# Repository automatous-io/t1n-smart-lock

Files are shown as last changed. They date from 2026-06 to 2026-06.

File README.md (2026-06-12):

# T1N Smart Lock

The T1N Smart Lock is an open source Matter over Thread device designed
for the 2005 Dodge Sprinter 2500 (T1N chassis). It adds what the van never
had: lock and unlock from your iPhone, lock state you can see at a glance,
and a sensor for any door left ajar. It does this without driving the lock
motors directly or replacing the factory module. The factory keys and key fob
keep working exactly as before.

The factory service manual identifies the wires, but does not describe reading
the lock-state LEDs, using the central timer module (CTM) rail to tell when the
van is asleep, or pulsing the locks once or twice depending on state. That approach
is the idea behind this project. Every signal and timing it depends on was worked out
by hand, with a multimeter at the back of the master door lock switch and a long stretch
of testing in the van. The manual gives you the pinout; it does not give you the design.

This device reports observed reality, not commanded state. So your app reflects what
the van actually did, not just what it was told to do.

<p align="center">
  <a href="docs/media/t1n-smart-lock-demo.mp4">
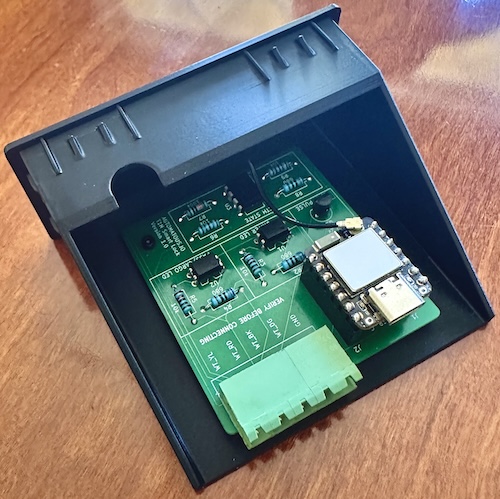
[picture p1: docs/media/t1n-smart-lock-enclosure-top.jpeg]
T1N Smart Lock in its 3D printed enclosure, top view
    
  </a>
  <br>
  <sub>Click to watch a short demo: opening/closing driver door, then locking and unlocking, with the master lock switch LEDs and Apple Home following each change.</sub>
</p>

It is built primarily for offgrid and vanlife use. It can run from either the
van's starter battery or a house/leisure battery; see
[INSTALL.md](docs/INSTALL.md#choosing-a-12v-source) for the tradeoffs.
It tolerates a noisy electrical environment including engine-on
conditions, and is a low-power Matter device so the power budget stays
small. It is local-first: it pairs and operates over Thread directly
from an iPhone 15 Pro or newer model featuring a Thread radio, and also
works through any compatible Thread Border Router for use in Apple Home,
Home Assistant, Google Home, or Alexa.

## How it works

The board is a small carrier for a Seeed Studio XIAO ESP32-C6, which
provides the Thread radio and runs the firmware. A transistor pulses
the factory master lock line, two optocouplers read the center console
switch LEDs without loading them, and a comparator turns the CTM sense
line into clean edges for sleep detection. The only connection to the
van is five wires tapped at the back of the master door lock switch,
landed on the board's five-position terminal block.

In your Matter app the device appears as a door lock plus two contact
sensors, one for the driver side and one for the passenger, cargo, and
rear doors. For the full architecture see [FIRMWARE.md](docs/FIRMWARE.md).

<p align="center">
  <a href="docs/media/t1n-smart-lock-home-with-doors.png">
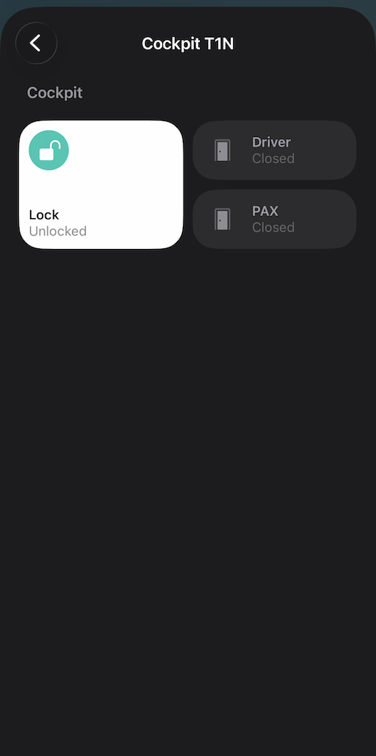
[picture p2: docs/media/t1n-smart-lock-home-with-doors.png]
The T1N Smart Lock in Apple Home, shown as a lock and two door sensors
    
  </a>
  <a href="docs/media/t1n-smart-lock-ha.png">
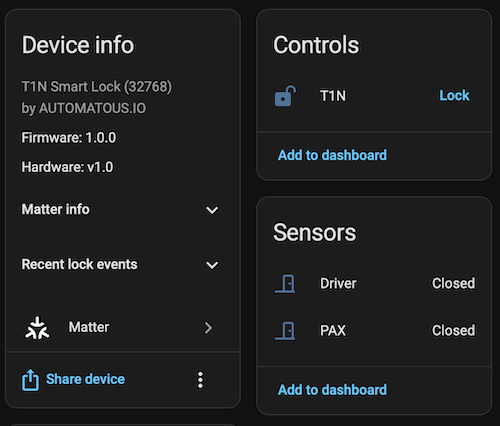
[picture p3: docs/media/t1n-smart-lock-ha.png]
The same lock paired in Home Assistant
    
  </a>
  <br>
  <sub>The same lock in Apple Home and Home Assistant. Matter is multi-admin, so it pairs to more than one ecosystem at once (see <a href="docs/INSTALL.md#commission-the-device">Commission the device</a>).</sub>
</p>

## Documentation

Everything is in [`docs/`](docs/). A typical path is to read SAFETY
first, build the board and enclosure, flash the firmware, then
commission and install it in the van.

| Document | What's in it |
|---|---|
| [FIRMWARE.md](docs/FIRMWARE.md) | firmware architecture and behavior |
| [HARDWARE.md](docs/HARDWARE.md) | PCB design, BOM, and ordering |
| [ENCLOSURE.md](docs/ENCLOSURE.md) | 3D printed enclosure |
| [BUILDING.md](docs/BUILDING.md) | building and flashing the firmware |
| [INSTALL.md](docs/INSTALL.md) | commissioning and van installation |
| [SAFETY.md](docs/SAFETY.md) | electrical and operational safety |
| [CERTIFICATION.md](docs/CERTIFICATION.md) | Matter/Thread certification status |
| [CONTRIBUTING.md](docs/CONTRIBUTING.md) | how to contribute |
| [LICENSING.md](docs/LICENSING.md) | license terms |

## Repository layout

| Path | Contents |
|---|---|
| [`firmware/`](firmware/) | C++ application on ESP-IDF (C/C++), source in `main/` |
| [`hardware/`](hardware/) | KiCad project, schematic, and gerbers |
| [`enclosure/`](enclosure/) | 3D printed enclosure model files |
| [`docs/`](docs/) | all project documentation |

## Status and compatibility

This is v1.0 of a personal project, developed and
tested by a single maintainer. It is an uncertified Matter device that
uses public test credentials, which is normal for a self-built device
and explained in [CERTIFICATION.md](docs/CERTIFICATION.md). Response
times on issues vary.

The firmware was developed and verified against one vehicle.
Compatibility with any other year, market, or trim is unconfirmed. If
you run it on a different T1N, a compatibility report is welcome. The
list below will grow as verified reports come in.

| Vehicle | Market | Status | Notes |
|---|---|---|---|
| 2005 Dodge Sprinter 2500 | North America | Verified | Reference build |

Firmware, PCB, and enclosure version history, and which revisions are
validated to work together, are recorded in [CHANGELOG.md](CHANGELOG.md).

## Safety

Installing this device modifies your vehicle's electrical system and
interfaces with the factory locking system. Wiring errors can damage
the CTM or the board. Read [SAFETY.md](docs/SAFETY.md) before building
or installing anything.

## Other projects from Automatous

| Project | What it is |
|---|---|
| [shelly-1-gen4-matter-thread](https://github.com/automatous-io/shelly-1-gen4-matter-thread) | open source Matter over Thread firmware for the Shelly 1 Gen4 |

## Licensing

This repository is multi-licensed. The firmware in `firmware/` is
[Apache 2.0](firmware/LICENSE.txt). The hardware in `hardware/` and the
enclosure in `enclosure/` are both CC BY 4.0
([hardware](hardware/LICENSE.txt), [enclosure](enclosure/LICENSE.txt)).
Both are open source. Use,
modification, sharing, and commercial use are all allowed, with
attribution. See [LICENSING.md](docs/LICENSING.md) for the plain
language version.

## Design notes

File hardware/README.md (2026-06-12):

# Hardware

KiCad design files and gerbers for the T1N Smart Lock PCB.
Licensed under [CC BY 4.0](LICENSE.txt).

See [HARDWARE.md](../docs/HARDWARE.md) for design notes, BOM, and
ordering instructions.

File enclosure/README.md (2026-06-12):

# Enclosure

3D printable enclosure that houses the T1N Smart Lock PCB and drops
into the factory center console opening. Designed for the T1N
center console; fit verified on a 2005, other years 2002 to 2006 should match but are
unconfirmed.

Licensed under [CC BY 4.0](LICENSE.txt).

Files included:
- STL file for direct printing
- STEP file for modification in CAD software

See [ENCLOSURE.md](../docs/ENCLOSURE.md) for print settings,
material recommendations, and assembly notes.

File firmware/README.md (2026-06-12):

# Firmware

ESP-IDF firmware for the T1N Smart Lock, a Matter over Thread
smart lock. Source is in `main/`.
Licensed under [Apache 2.0](LICENSE.txt).

See [FIRMWARE.md](../docs/FIRMWARE.md) for architecture and
behavior, and [BUILDING.md](../docs/BUILDING.md) for building the
firmware from source.

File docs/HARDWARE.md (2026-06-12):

# Hardware

**[README](../README.md)** > **Hardware** · [Report an issue](../../../issues/new)

PCB design files, bill of materials, and ordering notes for the
T1N Smart Lock board. For the 3D printed enclosure that houses
this board, see [ENCLOSURE.md](ENCLOSURE.md). For what the
firmware running on it does, see [FIRMWARE.md](FIRMWARE.md).

> Hardware design files are licensed under
> [CC BY 4.0](../hardware/LICENSE.txt). See [LICENSING.md](LICENSING.md#hardware-and-enclosure)
> for what that allows.

<p align="center">
  <a href="media/t1n-smart-lock-assembled.jpeg">
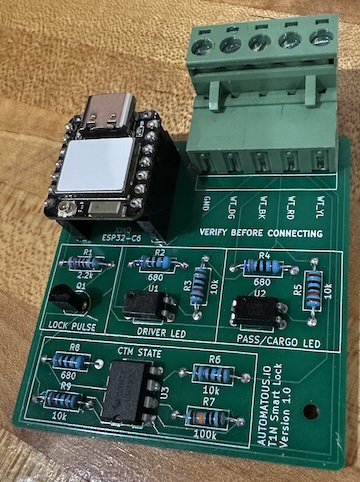
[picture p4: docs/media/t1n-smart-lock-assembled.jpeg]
Assembled board
    
  </a>
</p>

## What this board is

A small 2-layer carrier board for a Seeed Studio XIAO ESP32-C6.
The XIAO provides the Thread radio and runs the firmware; this
board adds the interface circuitry that lets the firmware observe
and command the Sprinter's factory central locking:

- A transistor output (Q1) that pulses the master lock line.
- Two optocouplers (U1, U2) that read the center console master door lock
  switch LEDs without electrically loading them.
- A comparator (U3) that turns the CTM's pulse-train sense line
  into clean digital edges for sleep detection.
- A 5-pin terminal block (J3) for the van-side wiring.

The XIAO is socketed on J1/J2, not soldered, so it can be swapped
or reflashed off-board. All components are through-hole and
hand-solderable. These are deliberate serviceability choices,
consistent across AUTOMATOUS.IO hardware and project designs.

## Board specifications

| Property | Value |
|---|---|
| Dimensions | 55.94 × 54 mm |
| Layers | 2 |
| Design tool | KiCad 10 |
| Controller | Seeed Studio XIAO ESP32-C6 (socketed) |
| Components | All through-hole, hand-solderable |
| Board revision | v1.0 |

## Schematic and layout

Design files live in `hardware/`:

- `hardware/kicad/`: KiCad 10 project (schematic + layout)
- `hardware/gerbers/`: fabrication outputs

[Schematic source (PNG)](../hardware/t1n-smart-lock-schematic.png) · [Schematic source (PDF)](../hardware/t1n-smart-lock-schematic.pdf)

## Power

> ⚠️ Connecting to vehicle 12V and the CTM carries real risks
> (miswiring, reverse polarity, CTM damage). Read
> [SAFETY.md](SAFETY.md) before wiring anything.

> The board draws ~0.3W continuously (~0.027A at 12V, measured at
> the buck input), since the Thread radio stays on. That is small
> enough to run from almost any 12V source. The reference build
> powers it from a 100Ah house/leisure battery. Whether a starter
> battery is also suitable depends on how often you drive; see
> [INSTALL.md](INSTALL.md#choosing-a-12v-source) for the tradeoff.

The board has no 12V input and no onboard 12V→5V stage. Power comes
in through the XIAO's USB-C connector, from an external buck
converter:

```
12V source  →  buck converter (12V → 5V, USB-C out)  →  XIAO USB-C
            →  XIAO onboard 5V→3V3 regulator  →  3V3 rail on this board
```

The 3V3 rail from the XIAO powers the optocoupler pull-ups and the
LM393. **12V never reaches this PCB.** J3 carries only the four van
signal wires plus ground; there is no power conductor on J3.

The buck converter is any quality automotive 12V→5V USB-C step-down.
Look for over-current and overvoltage protection; reverse-polarity
protection on the 12V input is also worth having, since a miswired
battery tap can otherwise damage the converter. It is external and
not part of this board's BOM.

## GPIO map

How the XIAO's pins connect to the board. This mirrors the pin
assignments in [FIRMWARE.md](FIRMWARE.md#hardware-interfaces).

| GPIO | Direction | Function | Circuit |
|---|---|---|---|
| 1 | Output | Master lock pulse | Drives Q1 base via R1 (2.2k) |
| 2 | Input | CTM sleep sense | LM393 (U3A) output, R9 pull-up |
| 18 | Input | Pass/cargo LED sense | PC817 (U2) collector, R5 pull-up |
| 20 | Input | Driver LED sense | PC817 (U1) collector, R3 pull-up |
| 3 | Output | RF switch enable | XIAO onboard antenna switch |
| 14 | Output | Antenna select (external U.FL) | XIAO onboard antenna switch |
| 15 | Output | Status LED | XIAO onboard LED |
| 9 | Input | Factory reset button | XIAO onboard BOOT button |

GPIO3, 14, 15, and 9 are internal to the XIAO module and do not
connect to this board's circuitry; they are listed for a complete
picture of pin usage.

## J3 terminal wiring

> ⚠️ Wiring errors can damage the CTM or board; see [SAFETY.md](SAFETY.md).

J3 is the only connection between the board and the van. The five
terminals, **in silkscreen order, left to right as printed on the board**,
are:

| Silkscreen | Signal | Connects to | Purpose |
|---|---|---|---|
| GND | Ground | Van chassis / CTM ground | Shared signal reference |
| WT_DG | Pass/cargo LED | Master door lock switch pass/cargo LED line | Read via U2 → GPIO18 |
| WT_BK | Driver LED | Master door lock switch driver LED line | Read via U1 → GPIO20 |
| WT_RD | CTM sense | CTM pulse-train line | Sleep detection via U3A → GPIO2 |
| WT_YL | Master lock | Master lock pulse line | Driven by Q1, pulsed from GPIO1 |

> The board silkscreen reads `GND · WT_DG · WT_BK · WT_RD · WT_YL`
> left to right. In the schematic, J3 pin 1 is `WT_YL` and pin 5 is
> `GND` (opposite order, since the connector is drawn from the other
> side). **Wire by the silkscreen, not the schematic pin numbers,**
> and confirm each signal before connecting. The board is printed
> `VERIFY BEFORE CONNECTING` for this reason. The `WT_*` labels are
> named for the factory wire colors they tap (Dodge base-with-tracer
> codes, so `WT_YL` is the white wire with a yellow tracer), but colors
> vary by year, market, and trim. Van-side wire colors, tap points, and
> the full wiring table are in [INSTALL.md](INSTALL.md#identifying-the-van-wires).

## Circuit blocks

**Master lock pulse (Q1).** GPIO1 drives the base of Q1 (PN2222A)
through R1 (2.2k). Q1's collector pulls the WT_YL master lock line
to ground for the pulse duration; the emitter is grounded. The
firmware drives GPIO1 low at init so the line is never floating
during boot (see `lock_pulse.cpp`). v1.0 has no base pull-down
resistor; float is handled in firmware.

**LED sense (U1, U2).** Each center console master-lock LED line drives
the input side of a PC817 optocoupler through a 680Ω series
resistor (R2 for driver/WT_BK, R4 for pass-cargo/WT_DG). The output
transistor pulls the GPIO low when the LED is lit, with R3 / R5
(10k) pulling the GPIO high otherwise. Optoisolation means the
board reads the LEDs without loading the van's wiring. U1 → GPIO20
(driver), U2 → GPIO18 (pass/cargo).

**CTM sleep detection (U3).** WT_RD carries a pulse train whose
frequency encodes whether the CTM is awake. R6 (10k) pulls WT_RD up
to the non-inverting input of comparator U3A (LM393). R7 (100k) and
R8 (680Ω) form a divider on the inverting input that sets the
comparison threshold. U3A's open-collector output drives GPIO2,
with R9 (10k) pulling the line up to 3V3, giving the firmware clean
digital edges to count. Only
half of the dual LM393 is used: U3A is active, U3B's inputs are
tied off, and U3C represents the shared power pins. Detail of the
firmware's edge-counting and sleep classifier is in
[FIRMWARE.md](FIRMWARE.md#what-the-firmware-observes).

## Bill of materials

### Board components

<p align="center">
  <a href="media/t1n-smart-lock-pcb.png">
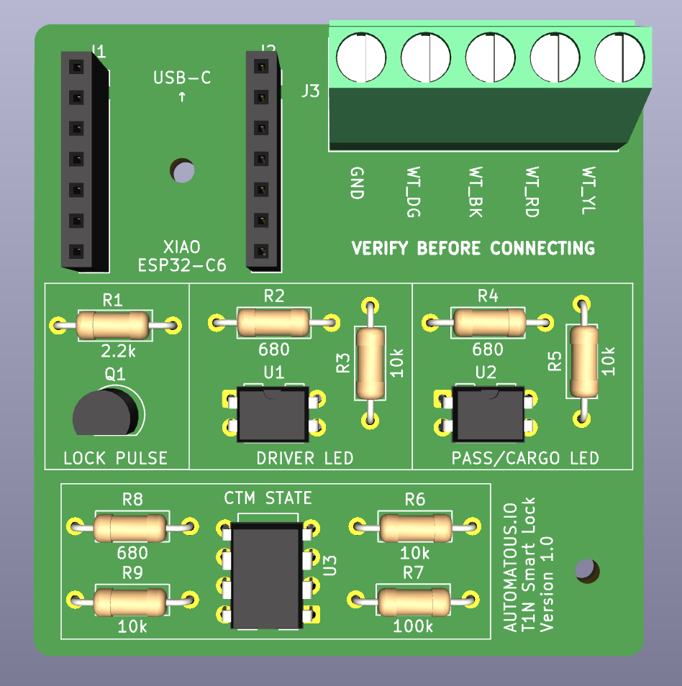
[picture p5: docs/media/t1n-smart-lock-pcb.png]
PCB render
    
  </a>
</p>

Soldered onto the PCB. All through-hole, hand-solderable.

| Ref | Qty | Type | Value | Footprint |
|---|---|---|---|---|
| J1, J2 | 2 | Socket header | 1×7, 2.54mm | PinSocket 1×07 P2.54mm vertical |
| J3 | 1 | Terminal block (see note) | 5.08mm, 5-pos | Phoenix MKDS-1,5-5-5.08 1×05 horizontal |
| Q1 | 1 | NPN transistor | PN2222A | TO-92 inline |
| R1 | 1 | Resistor | 2.2k | Axial DIN0207, P10.16mm |
| R2, R4, R8 | 3 | Resistor | 680Ω | Axial DIN0207, P10.16mm |
| R3, R5, R6, R9 | 4 | Resistor | 10k | Axial DIN0207, P10.16mm |
| R7 | 1 | Resistor | 100k | Axial DIN0207, P10.16mm |
| U1, U2 | 2 | Optocoupler | PC817 | DIP-4, W7.62mm |
| U3 | 1 | Dual comparator | LM393 | DIP-8, W7.62mm |

> **J3 terminal options.** The footprint is drawn for a fixed
> 5.08mm screw terminal (Phoenix MKDS). A 5.08mm *pluggable*
> terminal also fits the same pad pitch (with slight body overhang)
> and disconnects as a unit for easier service; the reference build
> uses this. Either works, pick your preference.

### External parts

Not soldered to the board; needed for a working install.

| Part | Notes |
|---|---|
| Seeed Studio XIAO ESP32-C6 | Seats into the J1/J2 sockets. Runs the firmware. |
| External antenna (U.FL / IPEX) | Connects to the XIAO's U.FL antenna connector. The firmware routes RF to the external antenna (see [FIRMWARE.md](FIRMWARE.md#module-map)), so this is required, not optional. |
| Buck converter, 12V→5V USB-C | Powers the XIAO from 12V source. Any quality automotive unit; see [Power](#power). |
| Inline fuse, ~1A | In the 12V feed close to the tap. Sized to the feed wire to protect the added wiring, not the board; see [INSTALL.md](INSTALL.md#powering-the-board). |

## Ordering the PCB

<p align="center">
  <a href="media/t1n-smart-lock-bare.jpeg">
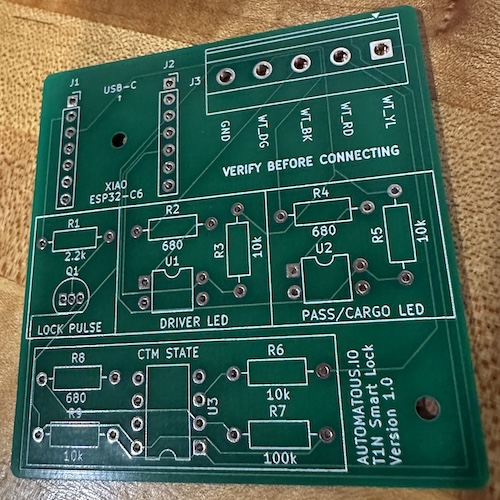
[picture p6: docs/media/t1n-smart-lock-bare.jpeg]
Bare PCB from fab
    
  </a>
</p>

The board was fabricated at JLCPCB from the gerbers in
`hardware/gerbers/`. Reference order: 30 pcs, 2-layer, standard
spec. Any 2-layer fab that accepts standard gerbers will work.
The board is hand-assembled; JLCPCB assembly is not required
since all parts are through-hole.

## Related documentation

- [README](../README.md) — project overview and quick start
- [FIRMWARE.md](FIRMWARE.md) — firmware architecture and behavior
- [ENCLOSURE.md](ENCLOSURE.md) — 3D printed enclosure
- [BUILDING.md](BUILDING.md) — building and flashing the firmware
- [INSTALL.md](INSTALL.md) — commissioning and van installation
- [SAFETY.md](SAFETY.md) — electrical and operational safety
- [CERTIFICATION.md](CERTIFICATION.md) — Matter/Thread certification status
- [CONTRIBUTING.md](CONTRIBUTING.md) — how to contribute
- [LICENSING.md](LICENSING.md) — license terms

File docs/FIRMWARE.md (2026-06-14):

# Firmware

**[README](../README.md)** > **Firmware** · [Report an issue](../../../issues/new)

This document explains the firmware architecture of the T1N Smart
Lock: how it observes vehicle state, how it commands the central
locking system, the design decisions that shaped the
implementation, and the validation that supports the v1.0 release.

The firmware runs on a XIAO ESP32-C6 and exposes the device to
Matter over Thread. It builds on Espressif's
[esp-matter](https://github.com/espressif/esp-matter) SDK and the
upstream OpenThread implementation. Application-specific code
lives in `firmware/main/`.

For the hardware this firmware drives, see
[HARDWARE.md](HARDWARE.md). For building and flashing, see
[BUILDING.md](BUILDING.md). For installation, see
[INSTALL.md](INSTALL.md). For safety, limitations, and failure modes,
see [SAFETY.md](SAFETY.md). A full list of related documents is in
[Related documentation](#related-documentation) at the end.

## Contents

- [Design philosophy](#design-philosophy)
- [Hardware interfaces](#hardware-interfaces)
- [Module map](#module-map)
- [Threading model](#threading-model)
- [The CTM model](#the-ctm-model)
  - [Stock CTM behavior](#stock-ctm-behavior)
  - [What the firmware observes](#what-the-firmware-observes)
  - [What the firmware commands](#what-the-firmware-commands)
  - [Why this approach](#why-this-approach)
- [The doors module](#the-doors-module)
  - [LED classification](#led-classification)
  - [Lock state derivation](#lock-state-derivation)
  - [Door state derivation](#door-state-derivation)
  - [Live vs stability-gated reads](#live-vs-stability-gated-reads)
  - [NVS persistence](#nvs-persistence)
  - [Blackout windows](#blackout-windows)
- [Lock command flow](#lock-command-flow)
  - [Command cooldown](#command-cooldown)
  - [Door open rejection](#door-open-rejection)
  - [Pulse count decision](#pulse-count-decision)
  - [The asymmetric pulse rule](#the-asymmetric-pulse-rule)
  - [Unlock command flow](#unlock-command-flow)
- [The pulse subsystem](#the-pulse-subsystem)
  - [Pulse width and sequence timing](#pulse-width-and-sequence-timing)
  - [Atomic single-sequence guarantee](#atomic-single-sequence-guarantee)
  - [Inter-sequence cooldown](#inter-sequence-cooldown)
  - [Boot-time safety](#boot-time-safety)
- [State reporting](#state-reporting)
  - [Observation push mechanism](#observation-push-mechanism)
  - [Optimistic write synchronization](#optimistic-write-synchronization)
  - [Eventual consistency](#eventual-consistency)
- [Building from source](#building-from-source)
- [Validation matrix](#validation-matrix)
- [Known limitations](#known-limitations)
- [Related documentation](#related-documentation)

## Design philosophy

The firmware is built on one core idea: report observed reality,
not commanded state.

Most aftermarket smart locks fire a command and assume it worked.
The Matter ecosystem then shows whatever the command requested,
which is correct most of the time and silently wrong the rest. A
pulse that didn't engage, a key fob that unlocked the van from
outside, a door that someone left open; these conditions silently
diverge from the optimistic state in the app.

The T1N Smart Lock takes a different approach. The Sprinter's
center console has master door lock switch (MLS) LEDs that already encode
the truth about lock and door state while the CTM is awake. The
firmware reads those LEDs the same way a human does, classifies
the patterns, and reports observed reality back to Matter. The
optimistic write from a Lock command is treated as a hypothesis
to be verified against observation, not a fact to be trusted.

This single decision shapes most of the architecture below. See
[SAFETY.md](SAFETY.md#what-the-firmware-adds-beyond-the-factory-system)
for how observation-first design bounds what the device can do wrong.

## Hardware interfaces

The lock and sensor interface uses four GPIO pins on the
ESP32-C6, each owned by a dedicated module (the antenna, status
LED, and reset button modules own additional pins, documented in
their own sections):

| GPIO | Direction | Module | Purpose |
|---|---|---|---|
| GPIO1 | Output | `lock_pulse` | Master lock pulse output |
| GPIO2 | Input | `ctm_state` | CTM sleep-detection signal |
| GPIO18 | Input | `doors` | PAX side MLS LED state |
| GPIO20 | Input | `doors` | Driver side MLS LED state |

GPIO ownership is exclusive; no module touches a pin that's owned
by another module. This keeps the interaction model clean and
makes it possible to reason about hardware safety properties
module by module.

The hardware design itself is documented in
[HARDWARE.md](HARDWARE.md), including the schematic, BOM, and
PCB layout. This document focuses on what the firmware does with
those signals.

## Module map

The firmware is organized into nine application-level modules
plus the Matter/CHIP stack provided by esp-matter:

**`app_main.cpp`** is the entry point. Configures Matter endpoints
(one door lock, two contact sensors), calls module init functions
in dependency order, starts the Matter stack.

**`lock_pulse`** owns GPIO1. Provides a non-blocking interface to
fire 1-pulse or 2-pulse sequences on the master lock line. An
internal worker task handles timing.

**`ctm_state`** owns GPIO2. Counts edges on the LM393 output,
applies a 5-second sliding window and sticky classifier, reports
whether the CTM is currently awake or asleep.

**`doors`** owns GPIO18 and GPIO20. Samples the MLS LEDs,
classifies each as SOLID, OFF, BLINK, or UNKNOWN, derives lock
and door states per side, persists state to NVS, pushes state to
Matter when observation diverges from the last reported value.

**`door_lock`** is the Matter Door Lock cluster glue. Receives
Lock/Unlock commands, applies command cooldown and door open
rejection, requests pulse sequences from `lock_pulse`, syncs the
optimistic state with the doors module's push tracker.

It also exposes `door_lock_init()`, an empty function whose only
job is to be called once from `app_main`. The cluster command
handlers (`emberAfPluginDoorLockOnDoorLockCommand` and friends)
are weak symbols that esp-matter resolves at link time; without
at least one symbol in this translation unit being referenced
directly, the linker would dead-strip the whole object file and
the handlers would silently vanish. The empty init call exists
only to anchor the file in the binary.

**`door_lock_manager`** holds credential, user, and schedule
storage for the Matter Door Lock cluster. The `BoltLockMgr` class
inside is vendored Espressif example code, used unchanged.
`door_lock` delegates PIN validation, credential operations, and
schedule management to this module.

**`status_led`** owns the XIAO ESP32-C6's onboard LED. Indicates
BLE advertising, Thread network state, and Matter Identify. The
blink patterns are tabulated in
[INSTALL.md](INSTALL.md#status-led-reference).

**`reset_button`** handles the factory reset button input. Clears
Matter commissioning data and restarts the device.

**`antenna`** routes the radio to the external U.FL antenna at boot:
GPIO3 enables the XIAO's onboard RF switch and GPIO14 selects the
external antenna over the built-in ceramic chip. It runs before the
Matter stack starts so the radio comes up on the right antenna, and
has no runtime behavior after that. The external antenna is what
extends Thread range, keeping the lock reachable for direct local
control from an iPhone 15 Pro or newer model featuring a Thread
radio, with no hub, consistent with the local-first design.

Modules communicate through narrow, explicit interfaces. The
doors module subscribes to `ctm_state` events via callback; the
door_lock module calls `lock_pulse_request`, `ctm_state_is_awake`,
and several `doors_*` accessors. There is no shared mutable
state outside the modules' own atomic variables.

## Threading model

The firmware runs on FreeRTOS with the following task topology:

| Task | Priority | Period/Trigger | Module | Purpose |
|---|---|---|---|---|
| `app_main` | (boot only) | once | `app_main` | Initialize subsystems, start Matter |
| Matter/CHIP | (managed) | event-driven | esp-matter | Matter protocol stack |
| `lock_pulse` | 10 | semaphore-driven | `lock_pulse` | Fire pulse sequences |
| `ctm_monitor` | 5 | 1000ms tick | `ctm_state` | Edge counting, classifier update |
| `doors_sample` | 5 | 50ms tick | `doors` | LED sampling and classification |
| `status_led` | 5 | 100ms tick | `status_led` | LED pattern updates |

Plus interrupts:

| ISR | Source | Module | Purpose |
|-----|---|---|---|
| GPIO2 edge | LM393 transition | `ctm_state` | Timestamp ring buffer append |

**Priority rationale.** The Matter/CHIP task runs at its default
priority (managed by esp-matter). `lock_pulse` runs at priority
10, higher than background monitor tasks so pulse timing is not
preempted by routine sampling, but lower than the CHIP task so
Matter work is never delayed by a pulse sequence. Background
monitor tasks (`ctm_monitor`, `doors_sample`, `status_led`) all
run at priority 5, which is sufficient for their periodic work.

**Cross-task safety.** State shared between tasks uses
`std::atomic` (default sequentially consistent ordering), with
`volatile` for the ISR-shared edge-timestamp ring buffer and for
the status LED module's simple cross-task state flags. There are
no traditional locks in the application code; the Matter stack
manages its own synchronization internally. The doors module is
the only place where multiple tasks might race (the sampler task
updates state, the door_lock task reads classifier output for the
BLINK check), and that race is safe because the reads are
point-in-time snapshots without compound state.

**Callback contract.** Modules that accept callbacks
(`ctm_state_register_callback`, `lock_pulse_register_complete_cb`)
fire the callback from the module's own task context. Callbacks
must not block. Implementations either set a flag or post to a
queue and return immediately. Blocking a callback delays the
module's primary work for the entire system.

## The CTM model

The central timer module (CTM) is the Sprinter's body control
unit. It handles central locking, interior lighting, the alarm
system, key fob processing, and various other low-voltage
functions. The CTM is the only component the firmware
communicates with; the rest of the vehicle's electrical system is
untouched.

### Stock CTM behavior

The CTM operates in two states: awake and asleep.

**Awake** is the active state. The center console MLS LEDs are
illuminated according to lock and door state. The CTM accepts
master lock pulses on the WT_YL line, responds to key fob
commands, processes door switch inputs, and continues to drive
any active loads (interior lights, etc.). The WT_RD signal,
traditionally the passenger-side (front passenger, slider, and
rear cargo) lock-pulse line, carries a pulse train at roughly
89 Hz when awake. The firmware repurposes WT_RD as a read-only
sleep-detection signal and never drives it.

**Asleep** is a power-saving state. After approximately 15
minutes of inactivity (no door switch activity, no MLS press, no
key fob event, no ignition), the CTM transitions to sleep. The
MLS LEDs go dark. The CTM is still powered and listening but
consumes minimal current. The WT_RD signal carries a slower pulse
train at approximately 47 Hz; this is how the firmware detects
sleep state.

The 15-minute timeout is typical but not universal. Locking the
van from inside via the door handle latches appears to trigger a
faster transition to sleep in edge cases; the CTM treats this as
a "the user has secured the vehicle and is leaving" signal. Other
variations exist across model years and trim levels.

Wake transitions happen on any of: a key fob press, a master door lock
switch press, a door switch event (any door opening or closing),
the ignition being turned on, or a master lock pulse on WT_YL
(the firmware's only output, via GPIO1). A passenger-side pulse
on WT_RD also wakes the CTM, but the firmware only observes
WT_RD, it never drives it.

These triggers usually wake the CTM, but not always. After the module
has been asleep for an extended period, on the order of hours, a door
event that would normally wake it sometimes does not, apparently a
deeper power-conserving behavior. This has been observed in the field;
the threshold and exact conditions are not characterized. When it
happens, the firmware keeps reporting last-known state until some later
event does wake the CTM.

The CTM treats the master lock as a single group action. A pulse
on the WT_YL line toggles the lock state of all doors together;
there is no per-side control at this interface. Individual lock/unlock
via interior door handles works (mechanical override). These events
never appear on the WT_YL line; whether they update the MLS LEDs depends
on CTM state, as described under the doors module.

### What the firmware observes

The firmware passively reads three signals from the CTM:

**WT_RD pulse rate** (via LM393 on GPIO2). Edge counts over a
5-second window tell the firmware whether the CTM is awake (~448
edges) or asleep (~238 edges). The signal is continuous in both
states; the rate is what differs. See the `ctm_state` module for
the detection threshold and sticky classifier that filters
transients.

**Driver-side MLS LED** (via PC817 optocoupler on GPIO20). The
driver LED reflects driver side door state. The LED is solid on
when the driver door is closed and locked, off when closed and
unlocked, and blinking when open.

**PAX-side MLS LED** (via PC817 optocoupler on GPIO18). The
PAX side LED reflects the combined state of the front passenger
door, sliding cargo door, and rear cargo doors. All three are
wired to the same LED signal on the T1N, so the firmware
represents them as one logical group via a single Matter contact
sensor endpoint.

The firmware never writes to these signals. They are read-only
observations of the CTM's state.

### What the firmware commands

The firmware drives one signal:

**WT_YL master lock pulse** (via GPIO1). A pulse on WT_YL is what
the center console MLS button physically
produces when pressed. The CTM treats the firmware-driven pulse
identically to a button press. There is no protocol; the pulse is
a level-triggered request to toggle the master lock state.

Pulse duration is 500ms, matching the timing of a deliberate
button press. Pulse sequences (one or two pulses with a 500ms
gap) handle the two cases of "CTM awake, just toggle" and "CTM
asleep, wake then toggle."

### Why this approach

The decision to read LEDs and pulse a single line, rather than
talk to the CTM via CAN bus or replace the module entirely, is
deliberate. The safety consequences of this choice are detailed
in [SAFETY.md](SAFETY.md#what-the-firmware-adds-beyond-the-factory-system);
the design intent is summarized here.

**OEM-respectful.** No CAN bus injection, no module replacement,
no firmware modification of factory components. The CTM operates
exactly as Mercedes designed it. The smart lock is a peripheral
that observes and nudges; it is not a replacement for the
original system.

**Bounded blast radius.** A firmware crash, a PCB failure, a
botched OTA; none of these affect the factory locking. Remove
power from the device and the van behaves exactly as it did from
the factory. The factory key fob and interior key cylinders
continue to work in all cases.

**Passive observation.** The CTM doesn't know the firmware is
listening. There is no handshake, no authentication, no protocol
state that could get out of sync. The firmware reads the same
signals a human technician with a probe would read.

**Future maintenance.** The LEDs and pulse lines are
analog-domain signals, not protocol traffic that depends on a
manufacturer's continued support.

## The doors module

The doors module is the largest and most complex application
module. It samples the two MLS LEDs continuously, classifies
their patterns, derives lock and door states for each side,
persists those states across power loss, and pushes updates to
Matter when observation diverges from what the ecosystem
currently shows.

### LED classification

Each MLS LED encodes its side's state through one of four
observable patterns:

**SOLID** (steady on): the side is closed and locked. The LED
reads continuously on. (The PC817 pulls the GPIO low when the LED
is on; `led_read_logical_on` inverts this, so a lit LED is a
logical-high sample.)

**OFF** (no illumination): with CTM awake, the side is closed and
unlocked. With CTM asleep, the LED is simply dark and the state
is undetermined; sampling is suspended in this case.

**BLINK** (alternating): the side has at least one door open. The
LED toggles at roughly 1 Hz (~500ms half-period). Detection
requires temporal observation; a single GPIO read cannot
distinguish solid-on from the high phase of a blink cycle.

**UNKNOWN**: pre-init state, before any sample has been recorded.
The classifier returns UNKNOWN only while the history buffer is
empty.

The sampler task runs every 50ms, appending the raw on/off
reading to a 30-slot (1500ms) circular history. Each tick the
classifier walks the history newest-to-oldest, counting
transitions and measuring the length of the most recent
contiguous run, then evaluates in this order:

- **BLINK**: 2 or more transitions in the window. Two transitions
  means at least one full half-cycle is visible; a single
  transition could just be a one-time state change (OFF to SOLID)
  rather than a blink.
- **SOLID**: the newest contiguous run is high and at least
  `SOLID_CONFIRM_SAMPLES` (10 samples / 500ms) long.
- **OFF**: the newest contiguous run is low and at least
  `OFF_CONFIRM_SAMPLES` (4 samples / 200ms) long. The shorter
  confirm time reflects OFF being the safe default.
- **Otherwise**: the classifier holds its previous value (no
  change). This cleanly bridges the brief transient between SOLID
  and OFF.

UNKNOWN is not a steady-state output; it appears only at first
boot before any sample exists. The 1500ms window is longer than
one full blink period, so a blinking LED always shows the two or
more transitions needed to classify as BLINK.

### Lock state derivation

Lock state is binary at the Matter endpoint level: LOCKED or
UNLOCKED. The full state space includes UNKNOWN for the
pre-classifier window at first boot.

Per-side lock state is derived from the LED classifier:
- SOLID = side is locked
- OFF (with CTM awake) = side is unlocked
- OFF (with CTM asleep) = sampling suspended, last-known value
  held
- BLINK = side has a door open; treated as unlocked (0) and
  committed through the same stability gate as OFF (an open door
  means the side is not locked)
- UNKNOWN = no commitment yet

The vehicle-level lock state combines both sides: the van is
LOCKED only when both driver and PAX last-stable-locked values
are 1 (both sides solidly locked, no doors open). Any other
combination reports UNLOCKED. Once both sides have committed a
stable reading after first boot, UNKNOWN can never reappear at
the vehicle level.

Manual single door lock/unlock via the interior door handle
appears to be observed only when the CTM is awake and driving the
MLS LEDs (for example, just after a door switch event). When the
CTM is asleep, as it is after the van has sat idle, even with
someone inside, the LEDs stay dark, so the firmware cannot see
the change until the next observable lock event (MLS press, key
fob, door cycle, or a pulse from this module).

### Door state derivation

Door state is binary per side: OPEN or CLOSED. Derived from the
classifier output:
- BLINK = door open
- SOLID or OFF = door closed
- UNKNOWN = no commitment

The two Matter contact sensor endpoints (driver and PAX) report
this state. The PAX endpoint represents the combined state of
the front passenger door, sliding cargo door, and rear cargo
doors, since they share a single LED signal on the T1N.

### Live vs stability-gated reads

The doors module exposes two kinds of accessors for each state:

**Live classifier reads** (`doors_driver_classifier_is_blink`,
`doors_pax_classifier_is_blink`) return the current classifier
output. These reflect physical reality within one classifier
window (~1.5 seconds) but include transient states the classifier
hasn't yet stabilized on.

**Stability-gated reads** (`doors_driver_is_open`,
`doors_pax_is_open`, `doors_driver_is_locked`,
`doors_pax_is_locked`, `doors_vehicle_is_fully_locked`,
`doors_compute_lock_state`) return the committed stable value.
These require 10 seconds of consistent classifier output before
committing to a new value.

The 10-second stability gate filters out the CTM's pre-sleep LED
fade-down window (observed ~8 seconds between LED dim and the
CTM officially sleeping). Without the gate, the classifier would
push wrong states to Apple Home or Home Assistant as the LEDs
fade during the transition to sleep.

Cost: legitimate door open/close events lag in the Matter
ecosystem by up to 10 seconds. This is acceptable because users
are typically not watching the app at the moment they open or
close a door. The lock command pre-check uses the live read
instead, so a freshly-closed door is accepted within ~1.5 seconds
rather than the full 10-second gate.

### NVS persistence

Both lock state and door state are persisted to NVS per side.
Writes go through the stability gates: a classifier transition
must hold continuously before being committed to the in-RAM
`last_stable_*` field and written to NVS.

NVS persistence serves two purposes:

**Boot-time state recovery.** At boot, the firmware reads the
persisted state before the classifier has accumulated history.
Apple Home or Home Assistant sees the last-known state
immediately rather than UNKNOWN. After the classifier window
settles, persisted values are verified or updated against fresh
observation.

**Survival of CTM sleep with state changes.** If a door is opened
while the CTM is asleep, the LED is dark and the firmware cannot
observe the change. The persisted state holds the last-known
value until the CTM wakes and the gate commits to the new value.

NVS writes are bounded. Lock state changes maybe 2 to 10 times
per day in typical van use. Door state may change 20 to 40 times
per day from in-and-out events. Combined writes stay well under
NVS wear limits over a 10+ year lifetime.

### Blackout windows

LED-affecting events generate transient activity that the
classifier would otherwise interpret as fake state changes. All
blackouts use a 1500ms window (one full classifier window):

**CTM asleep to awake.** The LEDs power on with transient
activity as the CTM resumes driving them. The doors module
subscribes to `ctm_state` wake events and starts a blackout on
each wake.

**CTM awake to asleep.** The LEDs fade out with transient
activity. NVS already has the right value from continuous writes
before sleep, so the blackout protects against misclassifying
the fade-down.

**Boot.** The first sampling window after init; the classifier
hasn't accumulated history yet.

**Post-pulse** (exported but not currently called). After a lock
pulse sequence completes, the LEDs transition between states
with brief intermediate activity. A future `lock_attempt` module
will start a blackout here.

During blackout, the classifier still runs internally
(accumulating history) but no Matter pushes occur. After
blackout, the settled state is pushed once.

## Lock command flow

Lock and Unlock commands enter through Matter Door Lock cluster
callbacks (`emberAfPluginDoorLockOnDoorLockCommand`,
`emberAfPluginDoorLockOnDoorUnlockCommand`). Both flow through
the same internal logic with one key difference: only the Lock
command has a door open pre-check.

End to end, a Lock tap moves through these stages, each detailed
in the subsections below:

1. Command cooldown check (reject if within 2s of the last
   command)
2. Door open pre-check (reject if either side reads BLINK)
3. Pulse count decision (1 or 2 pulses, from CTM state and the
   asymmetric rule)
4. Enqueue the sequence via `lock_pulse_request` (non-blocking)
5. `BoltLockMgr` optimistic write of LOCKED to the Matter
   attribute
6. Sync the doors push tracker and open the 25s quiet window
7. Pulses fire asynchronously; observation later confirms the
   optimistic write or issues a correcting push

Unlock follows the same path without step 2.

**AutoRelock.** `app_main` sets the Door Lock cluster's
`AutoRelockTime` to 0, disabling auto-relock. This is deliberate:
auto-relock-while-loading would lock users out mid-task during
the long in-and-out activity typical of vanlife. esp-matter does
not persist this attribute, so it also resets to 0 on every
reboot, which, given the default-off choice, is a non-issue
rather than a bug.

### Command cooldown

A 2-second cooldown is enforced between consecutive Lock or
Unlock commands at the Matter cluster level. This debounces user
intent: mashed buttons, controller retries, double-tap behaviors
from various ecosystems.

The cooldown is shared between Lock and Unlock. Any command
suppresses subsequent commands of either type during the
cooldown window. This is intentional. A user who taps Lock then
immediately taps Unlock is probably confused or fighting an
automation; serializing the requests with a delay gives the
system time to actually respond to the first command.

The cooldown is separate from the hardware-level inter-sequence
cooldown in `lock_pulse` (300ms). Both apply, in series. The
command cooldown debounces user intent; the pulse cooldown
debounces hardware actuation.

### Door open rejection

For Lock commands only: if either side's live classifier reads
BLINK at command time, the command is rejected outright. No
pulse fires. The Matter ecosystem returns "No Response" to the
user immediately. This is the firmware's headline behavior beyond the
factory system; [SAFETY.md](SAFETY.md#what-the-firmware-adds-beyond-the-factory-system)
covers why it matters and how the stock CTM differs.

The check uses the live classifier rather than the
stability-gated value. A freshly-closed door is accepted within
~1.5 seconds instead of the full 10-second stability gate. The
inverse miss (door just opened, classifier hasn't updated yet)
is rare and caught by the observation push once the quiet
window expires (see [State reporting](#state-reporting)).

Unlock commands do not have the equivalent check. When a door is
open, the firmware already reports the van as unlocked through
the observation push, so Apple Home and Home Assistant show
UNLOCKED. The standard ecosystem toggle UI shows "Lock" as the
available action in that state; an Unlock tap with a door open
does not arise in normal use.

### Pulse count decision

If the door open check passes (or for Unlock, unconditionally),
the firmware enters `request_pulses_for_ctm_state`. This
function decides whether to fire 1 pulse or 2.

The decision uses two inputs:
- `ctm_state_is_awake()`: is the CTM currently awake?
- `doors_lock_state_needs_sync_pulse()`: are we in the specific
  asymmetric partial state that requires a sync pulse?

The matrix:

| CTM | Sync needed? | Pulses |
|-----|---|---|
| Awake | No | 1 |
| Awake | Yes | 2 |
| Asleep | (irrelevant) | 2 |

When the CTM is asleep, the first pulse wakes it and the second
toggles the lock. When the CTM is awake but the lock state is in
the asymmetric partial state, the first pulse syncs both sides
to a known state and the second toggles to the target. Otherwise,
one pulse is enough.

### The asymmetric pulse rule

The T1N CTM treats the PAX side as authoritative for partial lock
states. When the van is in a partial state (one side locked, one
unlocked) and a single pulse is fired, the CTM syncs the driver
side to match PAX, not the other way around.

The implications:

**Driver SOLID + PAX OFF** (driver locked, PAX unlocked): a
single pulse would sync driver down to unlocked, opposite of user
intent. The firmware fires 2 pulses instead: pulse 1 syncs both
to unlocked, pulse 2 toggles both to locked. Net result: van
fully locked on one Lock command.

**Driver OFF + PAX SOLID** (driver unlocked, PAX locked): a
single pulse correctly syncs driver up to locked. Both sides end
up locked. Standard 1-pulse path.

**Both SOLID or both OFF**: no asymmetry, standard 1-pulse path.

**Either BLINK or UNKNOWN**: the asymmetric rule does not apply
(states aren't definitively in the partial pattern), default to
1-pulse path. The door open rejection has already filtered out
the BLINK case for Lock commands.

The `doors_lock_state_needs_sync_pulse` function encodes this
logic, returning true only for the driver-SOLID PAX-OFF case.

This rule was characterized through hardware testing. Earlier
firmware versions used a simpler always-1-pulse path and
exhibited the "tap Lock, get fully unlocked" failure mode in
partial states. The 2-pulse sync handles the asymmetry cleanly.

### Unlock command flow

Unlock commands follow the same path minus the door open check:

1. Command cooldown check
2. `request_pulses_for_ctm_state` (same pulse count logic, which
   internally calls `lock_pulse_request` to enqueue pulses)
3. Update `BoltLockMgr` in-memory state to UNLOCKED
4. Sync the doors push tracker with the optimistic write
5. Mark cooldown complete

The shared `request_pulses_for_ctm_state` means Unlock also
benefits from the asymmetric pulse rule. An Unlock command in
the driver-SOLID PAX-OFF state would fire 2 pulses (pulse 1 syncs
both to unlocked, pulse 2 toggles to locked, which is opposite
of Unlock intent).

This is intentional: the CTM is a toggle, not a state machine.
The firmware doesn't track "what direction does this pulse
move?" It only tracks "what sequence of pulses produces the
target state from current state?" For Unlock, the target is
UNLOCKED, and the sequence is whatever produces that from the
current observed state.

In practice, this means Unlock commands from partial states may
produce counterintuitive behavior. The Matter ecosystem will
correct via the observation push, so the user sees the truth
eventually. Future work could split the pulse logic into
direction-aware paths.

## The pulse subsystem

The `lock_pulse` module is the bottom layer of the lock command
stack. It owns GPIO1, fires pulse sequences with deterministic
timing, and provides safety guarantees against unintended
actuation.

### Pulse width and sequence timing

Three timing constants govern pulse behavior:

```
PULSE_WIDTH_MS       = 500
CTM_WAKE_DELAY_MS    = 500
SEQUENCE_COOLDOWN_MS = 300
```

**Pulse width** (500ms) is the duration GPIO1 is held HIGH for
each pulse. This matches the timing of a deliberate MLS button
press, ensuring the CTM treats the firmware pulse identically to
a human press.

**Wake delay** (500ms) is the gap between pulse 1 and pulse 2 in
a 2-pulse sequence. This matches the CTM's documented wake
latency: pulse 1 wakes the CTM, the wake delay gives the CTM
time to be ready to receive a lock command, and pulse 2 acts.

**Sequence cooldown** (300ms) is the minimum gap between the end
of one sequence and the start of the next. This is hardware-
level debounce; it prevents back-to-back sequences from cycling
the CTM faster than its electronics expect.

All three are compile-time constants. The firmware cannot
accidentally hold the line high indefinitely; `vTaskDelay`
provides deterministic timing, and the GPIO is driven LOW
immediately after the timed delay completes.

### Atomic single-sequence guarantee

The `lock_pulse_request` function uses an atomic
compare-and-exchange on a `s_busy` flag to ensure only one pulse
sequence runs at a time:

```cpp
bool expected = false;
if (!s_busy.compare_exchange_strong(expected, true)) {
    return LOCK_PULSE_RESULT_SUPPRESSED_BUSY;
}
```

This is the false-to-true transition. If `s_busy` is already
true, the compare-and-exchange fails and the request is rejected
with a logged warning. Subsequent requests during an active
sequence cannot interleave, interrupt, or stack.

The flag is cleared by the worker task after the sequence
completes, before the completion callback fires. A callback that
itself enqueues another sequence will succeed if the cooldown
allows.

### Inter-sequence cooldown

After a sequence completes, the next sequence cannot start until
`SEQUENCE_COOLDOWN_MS` (300ms) has elapsed. This is checked
before the busy flag claim, so a cooldown rejection doesn't
temporarily lock out other state:

```cpp
int64_t since_last_us = now_us - s_last_sequence_end_us.load();
if (since_last_us < (int64_t)SEQUENCE_COOLDOWN_MS * 1000) {
    return LOCK_PULSE_RESULT_SUPPRESSED_COOLDOWN;
}
```

This protects against rapid back-to-back actuation requests from
buggy controllers, malicious automation, or network retry storms.
The CTM expects time between actuations; the firmware enforces
that minimum.

### Boot-time safety

`lock_pulse_init` runs before `esp_matter::start` in `app_main`.
This ordering is important: the GPIO is configured and driven
LOW before any Matter code can possibly fire a callback that
could request a pulse.

The init sequence:
1. Configure GPIO1 as OUTPUT with internal pull-down enabled
2. Drive GPIO1 LOW explicitly (`gpio_set_level(GPIO, 0)`)
3. Create the work semaphore
4. Spawn the worker task

The pull-down enable plus the explicit LOW drive is redundant
safety. The line is never floating high during the brief window
where the ESP32 is configuring its peripherals but Matter hasn't
yet taken control. A floating line could otherwise cause a
spurious pulse during the boot sequence.

## State reporting

The doors module owns state reporting to Matter. The observation
push is the mechanism that makes "observed reality, not commanded
state" possible.

### Observation push mechanism

On each sampling tick (every 50ms), once past any active blackout
window, the doors module computes the current vehicle-level lock
state (and per-side door states) from the stability-gated values.
It compares this to the `last_pushed_*` tracker variables. If the
computed state differs from the last pushed state, it pushes the
new state to Matter and updates the tracker.

The push uses `DoorLockServer::SetLockState` for the lock
endpoint and the BooleanState cluster setter for the contact sensor
door endpoints. In esp-matter 1.5 the BooleanState cluster is
code driven: its `StateValue` is owned by the connectedhomeip
`BooleanStateCluster` object rather than the esp_matter attribute
store, so `esp_matter::attribute::update` returns
`ESP_ERR_NOT_SUPPORTED`. The push instead looks the cluster up in the
data-model provider registry
(`esp_matter::data_model::provider::get_instance().registry().Get`)
and calls `SetStateValue`, which writes the value, emits the
StateChange event, and marks the attribute dirty. Note that Matter's
BooleanState convention is inverted from intuition: `true` means
contact made (door closed),
so the push inverts the open state before writing it. Matter's
subscription machinery then propagates the state to subscribed
controllers (Apple Home, Home Assistant, etc.) within their
normal polling intervals.

### Optimistic write synchronization

When a Lock or Unlock command is received, the Matter Door Lock
cluster (via `BoltLockMgr`) optimistically writes the new state
to the LockState attribute. This is the "immediate feedback"
behavior that Matter expects: a successful command updates the
attribute immediately, before the device has physically actuated.

The doors module needs to know about this optimistic write,
otherwise its push tracker would think Matter still showed the
old state and would push a redundant update once observation
caught up.

The `doors_set_pushed_lock_state` function syncs the tracker
with the optimistic write. The Lock and Unlock command handlers
call this function after BoltLockMgr's state update. The flow:

1. User taps Lock
2. Command handler calls `request_pulses_for_ctm_state`
3. Command handler calls `BoltLockMgr().Lock(...)` which writes
   LOCKED to the Matter attribute
4. Command handler calls
   `doors_set_pushed_lock_state(LOCKED)` to sync the tracker
5. Pulses fire asynchronously
6. Observation eventually catches up: if reality matches LOCKED,
   no further push; if reality differs, the tracker mismatch
   triggers a correcting push to UNLOCKED

`doors_set_pushed_lock_state` also opens a lock-state push quiet
window (`LOCK_PUSH_QUIET_MS`, 25 seconds). During the window the
observation push skips lock-state updates (contact-sensor pushes
are unaffected). Without it, the stability gate's still-pre-pulse
value would push within one tick and cause a LOCKED to UNLOCKED
to LOCKED flicker in the app on every command. The 25-second
value covers the observed ~21-second command-to-stable-commit
latency (one pulse, CTM awake) plus margin; the 2-pulse wake
sequence adds about a second.

### Eventual consistency

The combination of optimistic writes, the observation push, and
the tracker sync provides eventual consistency: Matter converges
on reality after every change.

Sources of state change that the system handles:

**Firmware-initiated changes** (Lock/Unlock commands): optimistic
write happens immediately; the correcting push, if observation
later diverges, waits for the 25-second quiet window to expire
rather than the 10-second gate.

**External changes** (key fob press, MLS press, mechanical
unlock from inside): no optimistic write, observation pushes the
new state within 10 seconds of the LED transition stabilizing.

**Door state changes** (any door opened or closed): observation
pushes the new state within 10 seconds of the classifier
stabilizing on BLINK or non-BLINK.

The observation-driven window is dominated by the 10-second
stability gate. Faster reporting would require a shorter gate,
which would reintroduce false positives from the CTM's pre-sleep
LED fade-down. The 10-second tradeoff is calibrated against that
specific noise source.

## Building from source

Building the firmware from source and flashing it are covered in
[BUILDING.md](BUILDING.md). This section records only the resulting
image and its update story.

The v1.0 application image is about 1.54 MB. The partition layout
reserves 1.88 MB per application slot, so the binary uses roughly
82%. The build enables the Matter OTA requestor and uses a dual-slot
(A/B) flash layout, so the device is OTA-capable in principle. OTA is
untested in v1.0: no update has been validated through it, and the
reference workflow flashes over USB-C from source (see
[BUILDING.md](BUILDING.md#flash-your-build)). Treat OTA as present but
unsupported until a release validates it. Provider support also varies
by ecosystem (Home Assistant can serve Matter OTA, but not behind an
Apple Thread Border Router).

## Validation matrix

The v1.0 firmware was validated against eleven hardware scenarios on
a 2005 Dodge Sprinter 2500. Each test was performed manually with
serial logging attached, observing the actual behavior of the
CTM, the firmware, and the Matter ecosystem.

| # | Scenario | Expected | Result |
|---|---|---|---|
| 1 | Apple Home, no PIN, CTM awake, both sides locked, send Unlock | Single pulse fires, van unlocks, Apple Home shows UNLOCKED | PASS |
| 2 | HA, correct PIN, CTM awake, both sides unlocked, send Lock | Single pulse fires, van locks, HA shows LOCKED | PASS |
| 3 | HA, wrong PIN, send Lock | Command rejected at cluster level, no pulse fires | PASS |
| 4 | CTM asleep, both sides locked, send Unlock | 2-pulse sequence fires (wake + act), van unlocks | PASS |
| 5 | Partial state (driver SOLID, PAX OFF), send Lock | 2-pulse sync sequence fires, van fully locks | PASS |
| 6 | Partial state (driver OFF, PAX SOLID), send Lock | Single pulse fires, van fully locks | PASS |
| 7 | Slider open, send Lock | Command rejected, no pulse fires, "No Response" in Apple Home | PASS |
| 8 | Driver open, send Lock | Command rejected, no pulse fires, "No Response" in Apple Home | PASS |
| 9 | Power cycle with NVS persisted state | Boot reports last-known state, classifier confirms within window | PASS |
| 10 | CTM wake from sleep, blackout window | No false state pushes during 1500ms window | PASS |
| 11 | Rapid double Lock taps | Second tap rejected by 2s command cooldown | PASS |

These tests cover the primary functional and edge-case behavior.
They do not cover every possible state combination; partial-state
testing in particular has more permutations than were exercised.
Real-world usage will surface scenarios not in this matrix; bug
reports with serial logs are welcomed via
[GitHub issues](../../../issues/new).

## Known limitations

**Single CTM tested.** The firmware was developed and validated
against a single 2005 Dodge Sprinter 2500. Other model years,
trims, and regional variants may have different CTM behavior.
Compatibility reports from other configurations are welcomed.

**CTM sleep with door state changes.** While the CTM is asleep,
the LEDs are dark and the firmware cannot observe state changes.
A door opening or closing during sleep is invisible until the
CTM wakes. The persisted state holds the last-known value across
this window. Lock commands during this window may proceed past
the door open check if the door was opened during sleep.

**Intermittent classifier wedge after reboot with doors held open.**
If the van is rebooted while one or more doors have been
held open for several minutes, the classifier can read not-BLINK
for ~10 seconds after the CTM wakes despite the LEDs visibly
blinking, and commit a false CLOSED. It self-heals on the next
physical door event, and the hardware path is otherwise sound
(the same setup classifies correctly after recovery). Tracked in
a code TODO (observed 2026-05-31); a fix is pending. Serial logs
from any reproduction are welcome via
[GitHub issues](../../../issues/new).

**Post-pulse verification not implemented.** The firmware does
not currently verify that a pulse actually achieved the
commanded state. The observation push catches divergence, but a
true post-pulse verification module that explicitly waits for the
expected state would be more robust. See
`lock_pulse_register_complete_cb` for the hook point.

**No per-side unlock.** The CTM treats the master lock as a
group; there is no per-side actuation via the WT_YL line.
Removing the per-side pulse wire (in favor of using that GPIO
for CTM state detection) was a deliberate v1.0 tradeoff. Users
cannot unlock only the cargo doors while the slider is open;
they must close all doors, unlock the van, then open whichever
doors they need.

**Unlock with door open fires a pulse.** Because the Unlock
handler has no door open check, an Unlock command with a door
open will fire a pulse. The user-facing impact is bounded: the
ecosystem UI typically does not present Unlock as available in
this state, so the scenario is rare in practice. Future versions
may add a symmetric check.

**Manual interior lock/unlock may be invisible.** Locking or
unlocking a single door via the interior handle latch is
reflected only while the CTM is awake and driving the MLS LEDs;
for instance, right after a door cycle. When the CTM is asleep
(the van has been idle long enough to sleep, even if occupied),
the LEDs are dark and the firmware cannot observe the change; the
ecosystem is not updated until the next observable lock event.

## Related documentation

- [README](../README.md) — project overview and quick start
- [HARDWARE.md](HARDWARE.md) — PCB design, BOM, and ordering
- [ENCLOSURE.md](ENCLOSURE.md) — 3D printed enclosure
- [BUILDING.md](BUILDING.md) — building and flashing the firmware
- [INSTALL.md](INSTALL.md) — commissioning and van installation
- [SAFETY.md](SAFETY.md) — electrical and operational safety
- [CERTIFICATION.md](CERTIFICATION.md) — Matter/Thread certification status
- [CONTRIBUTING.md](CONTRIBUTING.md) — how to contribute
- [LICENSING.md](LICENSING.md) — license terms

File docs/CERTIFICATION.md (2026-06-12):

# Matter and Thread Certification

**[README](../README.md)** > **Certification** · [Report an issue](../../../issues/new)

This document explains the Matter and Thread certification status
of the T1N Smart Lock and what "uncertified Matter device" means
in practice.

## Certification status

This firmware is **not Matter Certified** and **not Thread Certified**.

It implements the Matter protocol via Espressif's
[esp-matter](https://github.com/espressif/esp-matter) SDK and
Thread via [OpenThread](https://openthread.io/), but has not been
submitted to the Connectivity Standards Alliance (CSA) or Thread
Group for certification.

## Why not certified

Matter and Thread certification are designed for commercial
products manufactured and distributed at scale. The process
requires paid membership in the certifying organization, per-product
certification fees, and testing through an authorized lab. Together
these run into thousands of dollars per year plus a per-device cost.

That cost structure is built for companies shipping volume products,
not for an open source design that individuals build for
themselves. The license allows selling a commercial version of the
hardware without asking permission (see
[LICENSING.md](LICENSING.md#hardware-and-enclosure)), so anyone who
did would take on certification as part of that.

## What this means for users

The device appears in Matter ecosystems as an uncertified Matter
device. Most ecosystems show a one time warning during
commissioning:

- **Apple Home:** "Uncertified Accessory" prompt with "Add Anyway"
- **Google Home:** "This device hasn't been certified" with an
  "Add anyway" option
- **Amazon Alexa:** Similar uncertified device prompt
- **Home Assistant:** May or may not prompt depending on version

This is normal and expected behavior. Tapping "Add Anyway" or the
equivalent option proceeds with commissioning. Once commissioned,
the device functions identically to a certified Matter device
within your fabric.

## Test credentials

The firmware uses the publicly available ESP-Matter test VID/PID.
These are standard development credentials published by the CSA for
non-commercial use during firmware development.

Because every unit built from this firmware uses the same test
credentials, they all share the same commissioning setup code and
QR. That is fine for personal use, but it means the setup code is
not a secret, and if you build more than one, commission them one
at a time to avoid ambiguity during pairing.

Once a device is commissioned to your Matter fabric, the setup
code is no longer used for authentication. Your Matter ecosystem
manages credentials going forward.

Test credentials are appropriate for personal use, development,
and open source distribution. They are not appropriate for any
commercial product, which would require obtaining a real VID/PID
from the CSA and certifying the device.

## Trademarks

- **Matter** is a trademark of the Connectivity Standards Alliance.
- **Thread** is a trademark of the Thread Group.

This project is not affiliated with, endorsed by, or sponsored by
either organization.

## Related documentation

- [README](../README.md) — project overview and quick start
- [FIRMWARE.md](FIRMWARE.md) — firmware architecture and behavior
- [HARDWARE.md](HARDWARE.md) — PCB design, BOM, and ordering
- [ENCLOSURE.md](ENCLOSURE.md) — 3D printed enclosure
- [BUILDING.md](BUILDING.md) — building and flashing the firmware
- [INSTALL.md](INSTALL.md) — commissioning and van installation
- [SAFETY.md](SAFETY.md) — electrical and operational safety
- [CONTRIBUTING.md](CONTRIBUTING.md) — how to contribute
- [LICENSING.md](LICENSING.md) — license terms

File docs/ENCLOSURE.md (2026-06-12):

# Enclosure

**[README](../README.md)** > **Enclosure** · [Report an issue](../../../issues/new)

3D printable enclosure that houses the T1N Smart Lock PCB and drops
into the factory center console opening of the Sprinter T1N. For the board
it holds, see [HARDWARE.md](HARDWARE.md).

> Enclosure files are licensed under
> [CC BY 4.0](../enclosure/LICENSE.txt). See [LICENSING.md](LICENSING.md#hardware-and-enclosure)
> for what that allows.

<p align="center">
  <a href="media/t1n-smart-lock-enclosure-front.jpeg">
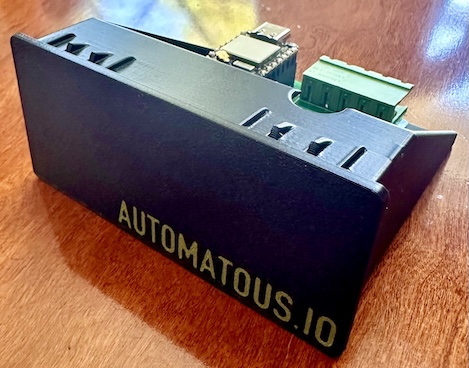
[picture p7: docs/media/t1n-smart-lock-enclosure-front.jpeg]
Board installed in enclosure
    
  </a>
</p>

## What this enclosure is

The enclosure is a single 3D printed part that the board drops into
from the top, with the XIAO's USB-C port and the J3 terminal both
accessible without removing the board after install. The entire back
is open to the inside of the center console, which doubles as ventilation (see
Thermal below).

The reference build prints in Polymaker PolyLite ASA with the "AUTOMATOUS.IO"
brand debossed on the front face and filled green.

## Enclosure specifications

| Property | Value |
|---|---|
| Outer dimensions | 89 × 41.5 × 75 mm (W × H × D) |
| Fits center console opening | ~89 × 41.5 mm (flush front face) |
| Material (reference build) | Polymaker PolyLite ASA |
| Revision | v1.0 |

## Files

- [`enclosure/t1n-smart-lock-enclosure.stl`](../enclosure/t1n-smart-lock-enclosure.stl) — ready to print
- [`enclosure/t1n-smart-lock-enclosure.step`](../enclosure/t1n-smart-lock-enclosure.step) — editable CAD source

Opening the STL on GitHub renders an interactive 3D preview in the
browser (rotate, pan, zoom), so you can inspect the part before
downloading or printing it. The STEP is the editable CAD source and
shows as text on GitHub rather than a 3D preview.

## Print settings

The reference build was printed with:

| Setting | Value |
|---|---|
| Printer | Bambu Lab H2D, 0.4 mm nozzle |
| Slicer profile | Bambu Studio "0.16mm Balanced Quality @BBL H2D" |
| Material | Polymaker PolyLite ASA |
| Layer height | 0.16 mm |
| Infill | 20%, gyroid |
| Supports | Not required |
| Bed orientation | Face down |

ASA warps if it cools unevenly, so print it in an enclosed chamber
and keep the print area free of drafts. A brim helps the corners
hold to the bed on a part this size. The reference build was printed
on an enclosed Bambu Lab H2D, which holds chamber temperature without
extra effort.

## Branding

The green "AUTOMATOUS.IO" on the front face is printed, not painted.
The text is debossed into the front face in the model, and the
reference build prints it as a second color on the H2D's dual nozzle:
black Polymaker PolyLite ASA for the body and Polymaker PolyLite ASA
Army Green for the recessed text, in one multicolor job
with the text faces assigned to the second nozzle. Reproducing the
look needs a dual-nozzle or AMS-capable printer. On a single-nozzle
printer, approximate it with a filament swap at the text layer or by
paint-filling the recess after printing.

## Assembly

<p align="center">
  <a href="media/t1n-smart-lock-enclosure-top.jpeg">
    Enclosure top view
  </a>
</p>

The board drops into the enclosure from the top, oriented so the
XIAO (USB-C end) and the J3 terminal face the open rear. Seated
this way, both the USB-C port and the terminal stay accessible from
the back for wiring, power, and reflashing once the unit is installed.

1. **Seat the board.** Lower the PCB into the enclosure so it rests
   on the internal ledge, XIAO and J3 toward the open rear. The two
   mounting holes in the PCB line up with the screw bosses in the
   floor of the enclosure.
2. **Secure it.** Drive two M2 self-tapping hex socket cap screws
   (M2 × 5mm) through the PCB mounting holes into the bosses. The
   reference build used screws labeled `HNA-M2-5-H` (M2, 5mm, hex
   socket cap, self-tapping). Snug, don't overtighten; self-tapping
   screws cut their own thread in the printed boss and stripping it
   is easy with too much torque.

That completes the bench assembly. Wiring to J3, powering the XIAO,
and seating the enclosure into the center console are covered in
[INSTALL.md](INSTALL.md).

## Fit

The enclosure is a friction fit into the factory center console opening where the
factory storage pocket sits, with the front face flush to the center console and no
modification to the vehicle required.

Fit is verified on a 2005 Dodge Sprinter 2500. Other T1N years
(2002 to 2006) use a similar center console but are unconfirmed; verify the
opening before printing a final version. Seating the enclosure in the
center console, removal, and van side wiring are covered in
[INSTALL.md](INSTALL.md#seating-the-enclosure-in-the-center-console).

## Thermal

The board draws ~0.3W (see [HARDWARE.md](HARDWARE.md#power)), so heat is
minimal. The fully open back vents into the center console cavity, which is more
than sufficient for a sub-1W load.

## Related documentation

- [README](../README.md) — project overview and quick start
- [FIRMWARE.md](FIRMWARE.md) — firmware architecture and behavior
- [HARDWARE.md](HARDWARE.md) — PCB design, BOM, and ordering
- [BUILDING.md](BUILDING.md) — building and flashing the firmware
- [INSTALL.md](INSTALL.md) — commissioning and van installation
- [SAFETY.md](SAFETY.md) — electrical and operational safety
- [CERTIFICATION.md](CERTIFICATION.md) — Matter/Thread certification status
- [CONTRIBUTING.md](CONTRIBUTING.md) — how to contribute
- [LICENSING.md](LICENSING.md) — license terms

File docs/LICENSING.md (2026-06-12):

# Licensing

**[README](../README.md)** > **Licensing** · [Report an issue](../../../issues/new)

The T1N Smart Lock is a personal project, shared so others can
build their own, and it is fully open source. The firmware carries
a software license and the physical design files carry a design
license, because the two kinds of files call for different license
families. Commercial use is allowed for every part, with
attribution, and you never need to ask permission.

## Firmware

The firmware in `firmware/` is licensed under
[Apache 2.0](../firmware/LICENSE.txt), a permissive open source
license approved by the Open Source Initiative. You can use it for
any purpose including commercial, modify it, and include it in
larger works whether open or closed, as long as you keep the
copyright notice and license text, state significant changes, and
include the NOTICE file if one is present.

The firmware started from Espressif's
[esp-matter](https://github.com/espressif/esp-matter) door lock
example. Those example files were released by Espressif into the
public domain under CC0, which places no conditions on reuse, so
the Apache 2.0 license here is a choice rather than something
inherited. One file, `firmware/main/common_macros.h`, is a genuine
Espressif source file that stays under Apache 2.0 with its original
notice. The firmware also builds against the esp-matter SDK and
other Espressif components, fetched at build time, which remain
under their own licenses, Apache 2.0 in most cases.

Apache 2.0 includes a patent grant, but it is a license from
contributors covering their own contributions, with a defensive
termination clause. It does not shield users from patent claims by
unrelated third parties.

## Hardware and enclosure

The PCB design files in `hardware/` (KiCad schematic, layout,
gerbers) and the 3D printed enclosure files in `enclosure/` (STL,
STEP) are licensed under
[Creative Commons Attribution 4.0](../hardware/LICENSE.txt), the
open, attribution-only Creative Commons license. You can build the
lock for yourself, modify the PCB or enclosure, share your changes,
order boards from a fabricator like JLCPCB, print enclosures, and
sell any of it, including assembled units and commercial products.
The only conditions are that you credit AUTOMATOUS.IO with a link back
to this repository and indicate where you changed the design.

CC BY 4.0 is not a software license, but it applies cleanly to
design files and creative work, and it keeps the physical design as
open as the firmware.

## Attribution

The standard attribution string for the firmware, the hardware, or
the enclosure is:

T1N Smart Lock by AUTOMATOUS.IO
https://github.com/automatous-io/t1n-smart-lock

Include it in any redistribution of the source files, in the README
of a fork or derivative project, in documentation that describes
work built on the project, and in promotional material for
derivative works.

## Related documentation

- [README](../README.md) — project overview and quick start
- [FIRMWARE.md](FIRMWARE.md) — firmware architecture and behavior
- [HARDWARE.md](HARDWARE.md) — PCB design, BOM, and ordering
- [ENCLOSURE.md](ENCLOSURE.md) — 3D printed enclosure
- [BUILDING.md](BUILDING.md) — building and flashing the firmware
- [INSTALL.md](INSTALL.md) — commissioning and van installation
- [SAFETY.md](SAFETY.md) — electrical and operational safety
- [CERTIFICATION.md](CERTIFICATION.md) — Matter/Thread certification status
- [CONTRIBUTING.md](CONTRIBUTING.md) — how to contribute

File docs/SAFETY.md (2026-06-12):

# Safety

**[README](../README.md)** > **Safety** · [Report an issue](../../../issues/new)

> **⚠️ Read before installing.** Installing this device modifies
> your vehicle's electrical system and interfaces with the
> factory locking system. Understand the limitations and accept
> the risks before proceeding.

This document covers what the T1N Smart Lock adds beyond the
factory system, its built-in safeguards, what it does not protect
against, what it requires from the user, known limitations, failure
modes, and disclaimers.

## What the firmware adds beyond the factory system

The firmware adds one behavior the factory module
doesn't have:

**Lock commands are rejected when a door is observed open.** The
firmware watches the master door lock switch (MLS) LEDs on the center console.
When any door is open, the LED for that side blinks while the
central timer module (CTM) is awake. If the firmware sees a blinking LED at the moment a Lock
command arrives, it rejects the command outright. No pulse fires. Apple
Home or Home Assistant returns "No Response" immediately, while
the user is still at the van and can close the offending door.

This check depends on the MLS LEDs being observable, so it functions
while the CTM is awake; when the CTM is asleep the LEDs are dark and
the open-door rejection cannot apply.

This isn't a personal-safety feature. It serves two practical purposes:

- **Honest state in the ecosystem.** Without the block, Apple
  Home or Home Assistant would briefly show LOCKED (the
  optimistic write) before the observation push corrects to
  UNLOCKED about 10 seconds later. That flicker is bad UX,
  especially in vanlife scenarios where users tap Lock and walk
  away. Rejecting at the command level gives immediate,
  accurate feedback.
- **Hardware preservation.** The T1N's master lock cycles all
  doors as a group. Firing a lock pulse while a door is open
  would ask 20-year-old actuators on closed doors to engage
  unnecessarily. Suppressing the command spares some wear,
  though the same actuators can still be cycled manually via
  the center console switch.

Unlock commands do not have the equivalent check by design.
When a door is open, the firmware already reports the van as
unlocked through the observation push, so Apple Home and Home
Assistant show UNLOCKED. The standard ecosystem toggle UI
shows "Lock" as the available action in that state, so the
scenario of a user tapping Unlock with a door open does not
arise in normal use.

More generally, the firmware reports observed reality rather
than commanded state. If any command does not produce the
expected outcome (for example, an unobserved physical
interference), the doors module sees the divergence and
corrects the reported state in Apple Home or Home Assistant
within about 10 seconds.

The factory T1N central locking will cycle the locks with the
slider or driver door wide open. The factory system never checks
door state before locking; the firmware adds that check so the
reported state stays honest and the closed-door actuators aren't
cycled needlessly.

## Built-in safeguards

Beyond the open-door check, the firmware is designed to prevent
unintended lock actuations. These are features the device gives
you. How each one is implemented is documented in
[FIRMWARE.md](FIRMWARE.md#the-pulse-subsystem).

**No spurious actuation at power-on.** During the brief window
between power-up and the firmware taking control, the lock line is
held in its safe, inactive state. Booting or rebooting the device
never trips the locks.

**Commands cannot double-fire.** Only one lock sequence runs at a
time. Overlapping or repeated commands from the Matter ecosystem
are rejected until the active sequence completes, so a burst of
taps or an automation loop cannot stack actuations.

**Rapid cycling is rate-limited.** A 300ms cooldown is enforced
between one lock sequence and the next, so buggy controllers,
malicious automation, or network retry storms cannot cycle the
locks faster than the CTM expects.

**The lock line cannot stick on.** Each pulse is a fixed 500ms and
the line returns to its inactive state immediately afterward. The
firmware cannot accidentally hold the lock line energized
indefinitely.

**State survives power loss.** After a reboot or power loss, the
device restores its last known lock and door state instead of
defaulting to "unknown" or "unlocked." That last known state is
what Apple Home or Home Assistant shows on boot. If nothing
changed during the outage, it is accurate right away; if a door
or lock did change, the device corrects the reported state once
the CTM wakes and the LEDs are observable again.

## What this device does NOT protect against

This is a smart locking retrofit. It does not protect against:

- **Forced entry.** Breaking a window, prying a door, or cutting
  through the body bypasses the locks entirely.
- **Key fob attacks.** Relay attacks, replay attacks, and other
  attacks against the factory key fob system are unaffected by
  this device. The factory immobilizer and remote keyless entry
  remain whatever they were before.
- **Theft of the entire vehicle.** A smart lock secures doors;
  it does not prevent hotwiring, tow away theft, or other
  whole vehicle theft methods.
- **Network-based attacks on Matter.** The Matter protocol has
  its own security model. This device inherits whatever security
  properties Matter and Thread provide; it does not add
  additional protections at the protocol layer.
- **Loss of remote control during network outages.** If your
  Thread Border Router, WiFi network, or internet connection
  is down, remote control is unavailable. Manual key access and
  the factory key fob continue to work normally.
- **Hardware failure of the factory locking system.** The smart
  lock interfaces with the factory central timer module. If the CTM
  or door actuators fail, the smart lock cannot compensate.

## What this device requires from the user

For safe operation:

- **Proper wiring.** The PCB connects to the Sprinter's central
  locking system via the five J3 terminals. Incorrect wiring can
  damage the CTM, the PCB, or both. Verify connections against
  [HARDWARE.md](HARDWARE.md#j3-terminal-wiring) before applying power.
- **An appropriately specified 12V power source.** The board is a
  constant load, drawing about 0.3W (~0.027A at 12V) whether or not
  the van is running. Choosing a source that suits how you use the
  van is your responsibility. The risk to avoid is draining a battery
  you rely on to start the engine. The reference build runs from a
  dedicated house / leisure battery (100Ah). Powering from the starter
  battery should be fine if you drive regularly, but to be safe use a
  separate house battery or add a low-voltage cutoff. See
  [Choosing a 12V source](INSTALL.md#choosing-a-12v-source) for the
  tradeoffs.
- **Overcurrent protection on the 12V power feed.** This applies only
  to the 12V line feeding the buck converter, not the five J3 signal
  taps, which are low-current CTM lines that never carry 12V. The 12V
  feed adds wiring that can chafe or short against the chassis, so put
  a small inline fuse (on the order of 1A, sized to the feed wire) in
  the 12V feed between the tap and the buck input, as close to the tap
  as practical. See
  [Powering the board](INSTALL.md#powering-the-board) for placement.
- **CTM compatibility verification.** The firmware was developed
  and tested against a single 2005 Dodge Sprinter 2500 CTM.
  Other model years, trims, and regional variants may have
  different CTM behavior. Test thoroughly before relying on
  the device.
- **A reliable Thread Border Router on the network.** The device
  requires a Thread Border Router within range of the van. Two
  control modes are possible depending on your setup:

  *Local control (at the van):* an iPhone 15 Pro or newer model
  featuring a Thread radio can serve as the Border Router
  while you're within Thread range of the van. This works without any
  other infrastructure and is sufficient if you only need to control
  the lock when you're physically near the vehicle.

  *Remote control (over the internet):* Requires a stationary
  Border Router at the van's typical parking location, connected
  to your WiFi network. A HomePod mini, Apple TV 4K, Nest Hub,
  Home Assistant with SkyConnect, or similar provides this. With
  this setup, Apple Home or Home Assistant, etc., can control the
  device from anywhere with an internet connection.

  For van use specifically, the stationary setup is strongly
  recommended if remote control matters to you. Local only control
  via iPhone is fine for commissioning and short-range use.
- **Factory key fob and physical key access.** Always keep the
  factory key fob accessible and physical keys available. Never
  rely solely on the smart lock to access the van.
- **Testing before depending on it.** Before treating the device
  as a primary locking control, exercise all lock and unlock
  scenarios manually. Confirm the center console LEDs match what the
  firmware reports.

## Year and regional caveats

The T1N (first generation Sprinter) was sold across multiple
years and markets:

- **Europe:** 1995 to 2006, as Mercedes-Benz Sprinter and
  Mercedes-Benz Transporter T1N
- **North America:** 2002 to 2006, as Freightliner Sprinter
  (from 2002) and Dodge Sprinter (from 2003)

This firmware was developed and tested on a single configuration:

- **2005 Dodge Sprinter 2500**, North American market

Compatibility with any other configuration is unverified.

Potential compatibility concerns:

- **Other T1N model years.** The CTM is broadly similar across
  model years but specific behaviors (sleep timing, LED blink
  patterns, wake response) may vary. Earlier production years
  (1995 to 2001) are particularly unverified and may differ.
- **European Mercedes-Benz Sprinter T1N.** Sold as Mercedes-Benz
  rather than Dodge. CTM hardware, wiring, and center console layout
  may differ from the North American Dodge variant.
- **Freightliner badged North American T1N.** Sold in North
  America alongside Dodge. Likely the same CTM as the Dodge
  variant but unverified.
- **NCV3 (2006 to 2018) and VS30 (2019+) Sprinters.** Newer
  Sprinter generations with different CTM protocols. This
  firmware is not designed or verified for these platforms.

If you're installing on anything other than a 2005 Dodge T1N,
expect to validate the CTM behavior yourself before relying on
the device. Hardware compatibility reports from other variants
are welcome via GitHub issues; the more reports come in, the
better the documentation can become.

## Failure modes

What happens when things go wrong:

- **ESP32 boot or firmware crash.** The device cannot send lock
  commands. The factory key fob and physical keys continue to
  work normally. The Matter ecosystem will show the device as
  unresponsive after a timeout.
- **Thread network loss.** The device retains its last known
  state in non-volatile storage and continues to read the CTM
  LEDs locally, but cannot be controlled remotely until the
  Thread network is restored.
- **Power loss to the device.** The device stops functioning.
  The factory locking system continues to work normally. On
  power restoration, the device boots fresh and re-attaches to
  the Thread network.
- **CTM sleep.** When the CTM enters sleep mode, the center console
  LEDs go dark and the device cannot observe state changes. It
  reports the last known state from before sleep until the CTM
  wakes back up. This is by design; the alternative is reporting
  "unknown," which is less useful for users who want to see
  consistent state.
- **CTM sleep with door state changes.** While the CTM is asleep,
  the firmware cannot observe LED changes and relies on last known
  state. Door state changes during sleep (a door opening or closing)
  are invisible until the CTM wakes. Commands issued during this window
  may not reflect actual conditions until observation resumes.
- **Firmware update interruption.** If a firmware update is
  interrupted, the device may fail to boot. Recovery requires
  physical access to the USB-C port to reflash the firmware.
  See [BUILDING.md](BUILDING.md#flash-your-build) for the reflash procedure.
- **PCB or component failure.** If the device fails entirely,
  remove power, disconnect from the CTM, and the factory
  locking system returns to its original behavior.

## Modifications and your van

Installing the T1N Smart Lock modifies your vehicle's electrical
system. Be aware:

- The factory warranty on T1N Sprinters has long expired by now,
  but any aftermarket extended warranty you may have could be
  affected by electrical modifications.
- Your vehicle insurance may have terms regarding aftermarket
  electrical modifications. Check with your insurance provider
  if you're unsure.
- Installation involves connecting to live vehicle electrical
  circuits. Inexperienced installers should consult a qualified
  technician.

## Disclaimer

This device is provided as-is, without warranty of any kind. By
building, installing, or using the T1N Smart Lock, you accept
all risks associated with modifying your vehicle and relying on
a smart locking retrofit.

AUTOMATOUS.IO is not liable for:

- Damage to your vehicle, its electrical system, or the factory
  CTM during installation or operation
- Loss, theft, or damage resulting from device malfunction,
  network outages, or any other failure of the device to
  perform as expected
- Personal injury or property damage arising from use of the
  device
- Insurance disputes, warranty disputes, or any other legal
  consequences of installing this device in your vehicle

This is an open source hardware project. It is not a certified
commercial product and carries no implicit guarantees of safety,
reliability, or fitness for any particular purpose. Whether you
build it from publicly available designs or order components, you
are responsible for the assembled device's installation and operation
in your vehicle.

If you're not comfortable with these terms, do not build or
install this device.

## Related documentation

- [README](../README.md) — project overview and quick start
- [FIRMWARE.md](FIRMWARE.md) — firmware architecture and behavior
- [HARDWARE.md](HARDWARE.md) — PCB design, BOM, and ordering
- [ENCLOSURE.md](ENCLOSURE.md) — 3D printed enclosure
- [BUILDING.md](BUILDING.md) — building and flashing the firmware
- [INSTALL.md](INSTALL.md) — commissioning and van installation
- [CERTIFICATION.md](CERTIFICATION.md) — Matter/Thread certification status
- [CONTRIBUTING.md](CONTRIBUTING.md) — how to contribute
- [LICENSING.md](LICENSING.md) — license terms

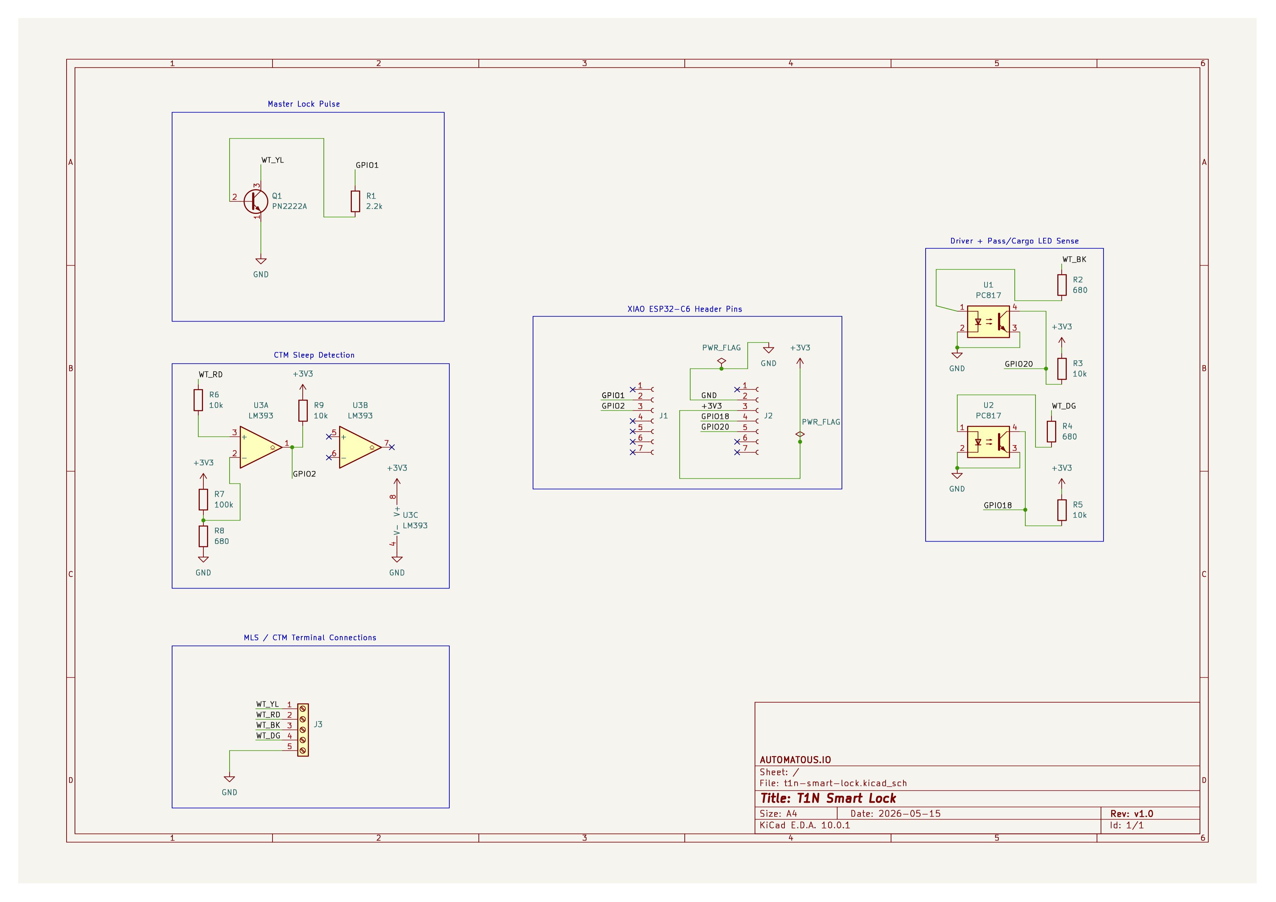
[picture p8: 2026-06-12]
hardware/t1n-smart-lock-schematic.png

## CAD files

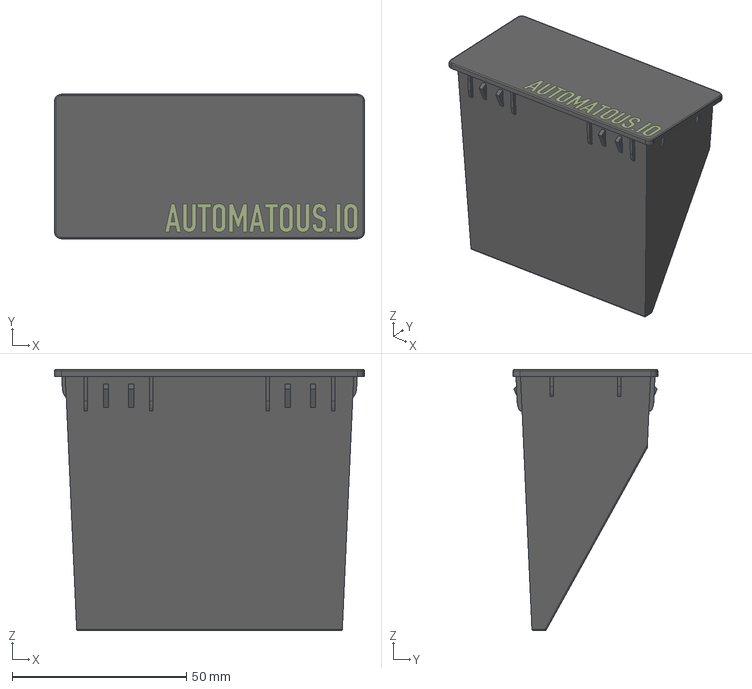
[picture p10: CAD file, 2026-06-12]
enclosure/t1n-smart-lock-enclosure.step
89.0 x 41.5 x 75.0 mm

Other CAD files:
enclosure/t1n-smart-lock-enclosure.stl

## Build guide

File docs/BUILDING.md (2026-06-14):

# Building from source

**[README](../README.md)** > **Building** · [Report an issue](../../../issues/new)

This guide covers building the T1N Smart Lock firmware from
source and flashing it to the board.

For what the firmware actually does once built, see
[FIRMWARE.md](FIRMWARE.md).

## Contents

- [Requirements](#requirements)
- [Repository structure](#repository-structure)
- [Setup](#setup)
- [Build](#build)
- [Build output](#build-output)
- [Flash your build](#flash-your-build)
- [Reproducing this exact build](#reproducing-this-exact-build)

## Requirements

- **ESP-IDF v5.4.4**. Espressif's IoT development framework, and
  the only SDK you install yourself. The esp_matter `1.5`
  release targets ESP-IDF 5.4.1; this project pins 5.4.4, the
  final 5.4.x patch release, which stays on the version line
  esp_matter expects and includes the 5.4.x bug fixes released
  after 5.4.1.
- **esp_matter, from the component registry**. Espressif's Matter
  SDK is pulled in automatically as a managed component, pinned to
  `1.5` in `main/idf_component.yml`. You do not clone or
  install esp-matter separately; the first build fetches it into
  `managed_components/`.
- **macOS or Linux**. The Windows build host is not tested.

## Repository structure

The firmware is a single ESP-IDF project rooted at `firmware/`:

```
firmware/
├── main/                 # application source (module map in FIRMWARE.md)
│   └── idf_component.yml  # registry component pins (esp_matter, button)
└── sdkconfig.defaults     # Thread/Matter build defaults for the C6
```

All build commands below run from inside `firmware/`.

## Setup

ESP-IDF is the only SDK to install yourself. Follow Espressif's
official guide for v5.4.4 and the ESP32-C6 target:

- [ESP-IDF Get Started (v5.4.4, ESP32-C6)](https://docs.espressif.com/projects/esp-idf/en/v5.4.4/esp32c6/get-started/index.html)

esp_matter and the other managed components are fetched from the
component registry on the first build, so there is nothing else to
install.

## Build

Clone the repository and build:

```bash
git clone https://github.com/automatous-io/t1n-smart-lock.git
cd t1n-smart-lock/firmware

# Activate the ESP-IDF environment. The export.sh path depends on
# where ESP-IDF was installed. Manual install:
. $HOME/esp/esp-idf/export.sh
# VSCode ESP-IDF extension installs under .espressif, e.g.:
# . $HOME/.espressif/v5.4.4/esp-idf/export.sh

idf.py set-target esp32c6
idf.py build
```

Run these in the same shell where you sourced `export.sh`;
ESP-IDF won't be on your PATH otherwise.

`sdkconfig.defaults` is applied automatically by `set-target`, so
no `-DSDKCONFIG_DEFAULTS` flag is needed. The first build resolves
the registry components pinned in `main/idf_component.yml` and
downloads them into `managed_components/`; this needs network
access and runs only once. After the target is set, plain
`idf.py build` rebuilds incrementally.

A successful build ends with `Project build complete.` followed by
the path to `t1n_smart_lock.bin` and the `idf.py flash` command
hint. If the build stops with an error instead, the most common
cause is an ESP-IDF version mismatch (see
[Requirements](#requirements)).

## Build output

`idf.py build` produces the application image and its supporting
binaries in `build/`:

- `build/t1n_smart_lock.bin`, the application image
- `build/bootloader/bootloader.bin`, the second-stage bootloader
- `build/partition_table/partition-table.bin`, the partition table

## Flash your build

With the board connected over USB-C:

**The first time you flash a given board, erase it first.** Erasing
clears the whole flash, including the `nvs` partition, so the board
starts from a known-empty state. A XIAO may arrive with factory demo
firmware, and a board you have used before can carry leftover NVS data,
Matter commissioning records, or Thread credentials from whatever ran
on it previously. Wiping all of it lets the device boot uncommissioned
and pair cleanly. This build
compiles its commissionable data and attestation certificates into the
firmware (test setup parameters and the example DAC provider), so
nothing needs re-provisioning after the erase and the pairing QR is
unchanged.

```bash
idf.py -p <PORT> erase-flash
idf.py -p <PORT> flash monitor
```

Replace `<PORT>` with the board's USB serial port:

- **macOS:** `/dev/cu.usbmodem*` (e.g. `/dev/cu.usbmodem101`)
- **Linux:** `/dev/ttyACM*` or `/dev/ttyUSB*`
- **Windows:** `COM*` (untested build host)

`idf.py flash` writes the bootloader, partition table, and app
image to their correct offsets automatically; there's no manual
merge step. The ESP-IDF VSCode extension's flash button does the
same thing if you prefer a GUI. Exit the serial monitor with
`Ctrl-]`.

**For later firmware updates, flash without erasing.** Plain
`idf.py -p <PORT> flash monitor` rewrites the bootloader, partition
table, and app image but leaves the `nvs` data partition intact, so the
device keeps its Matter fabric and Thread credentials and does not need
re-pairing after an update. To return a commissioned device to a fresh
state without a full erase, use the factory reset button (see
[INSTALL.md](INSTALL.md#factory-reset)) or erase only the `nvs` partition.

The fastest at-a-glance check is the onboard status LED: it blinks
while the device is pairing or attaching to Thread, and goes solid
once it's connected and operational. A solid LED is the healthy
resting state. See the [Status LED reference](INSTALL.md#status-led-reference)
in INSTALL.md for the full pattern table.

In the serial monitor, a healthy boot shows these in order:

- `Project name: t1n_smart_lock` and the expected `App version`,
  confirming your build booted rather than a stale image.
- Each module reporting ready (`lock_pulse`, `ctm_state`, and
  `doors: Doors module ready`), then
  `Door lock cluster initialized`.
- `Server initialization complete`.

A good flash leaves the board booting uncommissioned and advertising
over BLE, shown by a rapid blink on the status LED. That is the
expected resting state for a fresh board. Commissioning it to your
Matter ecosystem and wiring it into the van are covered in
[INSTALL.md](INSTALL.md).

## Reproducing this exact build

The Requirements above are enough to build working firmware. The
registry method also makes the exact build reproducible without any
manual SDK checkout. Three things pin it:

- **ESP-IDF v5.4.4**, the version this release was built with.
- **`main/idf_component.yml`**, which pins `espressif/esp_matter`
  to `1.5` and `espressif/button` to `^4`.
- **`firmware/dependencies.lock`**, which records the exact
  resolved version and content hash of every managed component,
  including esp_matter and its transitive dependencies.

To reproduce the release binary, build with ESP-IDF 5.4.4 against
the committed `dependencies.lock`; the component manager restores
the same versions from the registry. Delete `managed_components/`
and rebuild if you want to force a clean re-resolution against the
lock file.

## Related documentation

- [README](../README.md) — project overview and quick start
- [FIRMWARE.md](FIRMWARE.md) — firmware architecture and behavior
- [HARDWARE.md](HARDWARE.md) — PCB design, BOM, and ordering
- [ENCLOSURE.md](ENCLOSURE.md) — 3D printed enclosure
- [INSTALL.md](INSTALL.md) — commissioning and van installation
- [SAFETY.md](SAFETY.md) — electrical and operational safety
- [CERTIFICATION.md](CERTIFICATION.md) — Matter/Thread certification status
- [CONTRIBUTING.md](CONTRIBUTING.md) — how to contribute
- [LICENSING.md](LICENSING.md) — license terms

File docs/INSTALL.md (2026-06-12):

# Installation

**[README](../README.md)** > **Installation** · [Report an issue](../../../issues/new)

> **⚠️ Read [SAFETY.md](SAFETY.md) before you begin.** This install
> taps into your vehicle's wiring and the factory locking system.
> Wiring to the wrong conductor can damage the CTM, the board, or
> both. Wire colors and locations vary by year, market, and trim.
> Verify every wire in *your* van before connecting. You install
> this at your own risk.

This guide covers commissioning the assembled and flashed T1N Smart
Lock and fitting it into the van: pairing it to your Matter ecosystem
on the bench, choosing a power source, identifying and tapping the
factory wires, and seating the enclosure in the center console. For the board
see [HARDWARE.md](HARDWARE.md); for the enclosure see
[ENCLOSURE.md](ENCLOSURE.md); for building and flashing the firmware
see [BUILDING.md](BUILDING.md).

## Contents

- [Before you start](#before-you-start)
- [Commission the device](#commission-the-device)
- [Choosing a 12V source](#choosing-a-12v-source)
- [Identifying the van wires](#identifying-the-van-wires)
- [Connecting to the van wires](#connecting-to-the-van-wires)
- [Powering the board](#powering-the-board)
- [Seating the enclosure in the center console](#seating-the-enclosure-in-the-center-console)
- [Confirming it's connected](#confirming-its-connected)
- [Status LED reference](#status-led-reference)
- [Factory reset](#factory-reset)
- [Related documentation](#related-documentation)

## Before you start

This guide assumes you've already completed a couple of steps on the
bench:

- **Built or flashed the firmware and verified it runs.** See
  [BUILDING.md](BUILDING.md#flash-your-build).
- **Assembled the board into the enclosure.** See
  [ENCLOSURE.md](ENCLOSURE.md#assembly).

Commissioning comes next and is covered below. Do it on the bench
before wiring anything into the van.

Do not cut or tap any van wiring until the device is flashed,
commissioned, and confirmed working on the bench. A flash or
commissioning problem is trivial to fix on the bench. Once the unit
is installed it is still recoverable, the reference build uses a
quick-disconnect terminal and a USB-C plug so you can unwire it, but
you still have to pull the enclosure from the center console and
reflash, which is extra work you can avoid by getting it right first.

You'll also need:

- Connectors for the five signal and ground taps: five 3-conductor
  WAGO 221-series connectors for cut-and-splice (the reference build),
  or five T-taps for a reversible install (see [Connecting to the van
  wires](#connecting-to-the-van-wires)). Buy a few spares: the 12V feed
  (house battery or cigarette-lighter tap) and the inline fuse each
  need their own connectors too (see [Powering the
  board](#powering-the-board))
- A multimeter, basic hand tools (a screwdriver), and wire cutters
- Jumper wires for the board's five signal and ground leads.
  The reference build uses Dupont wires. These taps are low-power
  logic-level lines to the CTM, not the 12V supply, so thin jumper wire
  is adequate. The board takes its power over USB-C, where the buck and
  the XIAO step 5V down to 3V3; 12V never reaches these leads.
- A 12V→5V USB-C buck converter (see [HARDWARE.md](HARDWARE.md#power))
- A Thread Border Router reachable from the van (see
  [Confirming it's connected](#confirming-its-connected))

## Commission the device

Do this on the bench, with the board powered over USB-C, before you
wire anything into the van. Commissioning pairs the lock to your Matter
ecosystem and is stored on the device, so it carries over to the van
and you do not repeat it during the physical install.

Commissioning involves two roles, and people new to Matter over Thread
often conflate them because one device usually fills both. A Matter
controller is the ecosystem you pair the lock into and control it from:
Apple Home, Google Home, Amazon Alexa, or Home Assistant, running on a
phone or a home hub. A Thread Border Router is the radio bridge that
connects the lock's Thread network to your home IP network so the
controller can reach it. Both must be present and reachable on your
network during commissioning.

A single device can cover both needs. An iPhone 15 Pro or newer model
has its own Thread radio, so it can serve as the Matter controller and
reach the lock over Thread directly, with no separate Border Router or
hub. That is enough for local control while you are within Thread range
of the van. A stationary Border Router such as a HomePod mini, Apple TV 4K,
or Nest Hub 2nd gen keeps the Thread network reachable when your phone is away,
which adds remote control over the internet and supports automations. See
[SAFETY.md](SAFETY.md#what-this-device-requires-from-the-user) for the
local versus remote tradeoff.

BLE carries only the pairing handshake; the lock operates over Thread
once it has joined.

The pairing QR code and manual pairing code are saved at
[`media/matter_qrcode.png`](media/matter_qrcode.png) for convenience.
Every build of this firmware shares the same test credentials and
therefore the same code, so it is not a secret (see
[CERTIFICATION.md](CERTIFICATION.md)).

1. Power the board over USB-C and confirm the status LED is blinking
   rapidly (uncommissioned, see
   [Status LED reference](#status-led-reference)).
2. In your Matter app, add a device and scan the QR code or enter the
   manual pairing code.
3. This firmware ships with test attestation certificates, so the app
   warns that the accessory is uncertified. Accept it ("Add Anyway" in
   Apple Home). This is expected for a self-built device; see
   [CERTIFICATION.md](CERTIFICATION.md#what-this-means-for-users).
4. Wait for the device to join Thread. The LED moves from rapid blink
   to a slow blink while attaching, then goes solid once it is
   connected and operational.

On the bench the device accepts lock and unlock commands but cannot
observe the van's LEDs yet, so reported lock state is not meaningful
until it is wired in. Confirm it pairs and responds, then move on to
the wiring.

Matter is multi-admin, so you can add the lock to more ecosystems later
without starting over: from the app that already controls it, open a
new pairing window (the "add another app" or share option) to get a
fresh setup code, then commission from the second app. You do not
factory reset to add an ecosystem; a reset wipes every commissioned
fabric (see [Factory reset](#factory-reset)).

## Choosing a 12V source

The board draws ~0.3W continuously (~0.027A at 12V), since the
Thread radio stays on. This is a small but constant 24/7 load on
whatever 12V source feeds the buck converter, whether or not the van
is running.

**Recommended: house / leisure battery.** The reference build feeds
the buck from a 100Ah house battery. At 0.027A the draw is
negligible against that capacity and keeps the
lock available with zero impact on your ability to start the van.

**Starter battery: fine if you drive periodically.** The draw is
small enough that a starter battery tolerates it for weeks, not
hours, so this is reasonable if the van is driven every week or two.
The case to avoid is a van that sits unused for many weeks, or a
starter battery already aging or weak. If that's your situation, use
the house battery or add a low-voltage cutoff.

If in doubt, use the house battery.

## Identifying the van wires

> **⚠️ Confirm every wire in your own van.** The colors and
> locations below are from a 2005 Dodge Sprinter 2500. Other years,
> markets, and trims differ. Verify each wire's function with a
> multimeter before tapping it. A wrong tap can damage the CTM. See
> [SAFETY.md](SAFETY.md).

Each J3 terminal connects to one factory wire. The J3 signal names
and the board side are in [HARDWARE.md](HARDWARE.md#j3-terminal-wiring); this is the
van side.

| J3 signal | Function | Factory wire (2005 Dodge) | Location |
|---|---|---|---|
| GND | Ground | Chassis / CTM ground | Back of the MLS |
| WT_DG | Pass/cargo LED | White, dark green tracer | Back of the MLS |
| WT_BK | Driver LED | White, black tracer | Back of the MLS |
| WT_RD | CTM sleep sense | White, red tracer | Back of the MLS |
| WT_YL | Master lock pulse | White, yellow tracer | Back of the MLS |

The J3 terminals are named for these factory wire colors, in the
Dodge base-with-tracer convention (WT/YL, WT/RD, WT/BK, WT/DG). The
colors above are the reference build's 2005 Sprinter wiring. Confirm
each one with a multimeter before connecting, as the warning above
stresses.

All five connections are made at the back of the master door lock switch
(MLS), the lock-button cluster in the center console. The four signal wires and
ground all exit the MLS connector, so this one spot is the only place
you tap. Remove the MLS from the center console to reach the connector behind it,
identify each wire by the colors in the table above (metering to
confirm), then splice or T-tap there as described in [Connecting to the
van wires](#connecting-to-the-van-wires).

<p align="center">
  <a href="media/t1n-smart-lock-mls.jpeg">
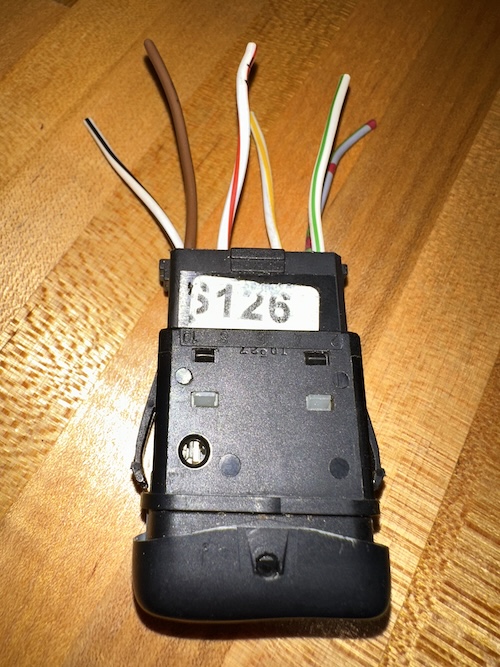
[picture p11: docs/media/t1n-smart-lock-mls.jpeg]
Master door lock switch on the bench, showing the wires to tap
    
  </a>
  <a href="media/t1n-smart-lock-mls-harness-disconnected.jpeg">
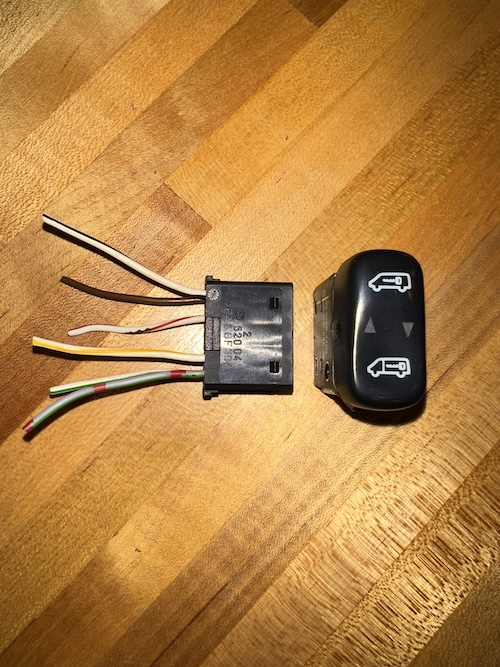
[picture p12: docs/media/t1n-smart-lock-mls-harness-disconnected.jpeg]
MLS with its factory harness disconnected
    
  </a>
</p>

The factory service manual is useful for cross-referencing wire
functions and connector pinouts. It is copyrighted, so it is not
included in this repository. A copy of the 2006 Sprinter service
manual is hosted at
[diysprinter.co.uk](https://diysprinter.co.uk/reference/2006-VA-SM.pdf),
with more reference documents in their [reference
index](https://diysprinter.co.uk/reference/). The 2006 manual is
close enough to the 2005 reference build for wiring cross-reference,
but confirm every wire in your own van with a multimeter regardless.

## Connecting to the van wires

Each signal wire plus ground needs a tap into the corresponding
factory wire. Two approaches, depending on whether you want the
install to be reversible:

**Cut-and-splice (reference build).** Cut the factory wire and join
both ends plus the board's lead with a 3-conductor lever connector
(the reference build used a WAGO 221-series connector).
Solid and vibration-resistant. The tradeoff is permanence: the
factory wire is cut, so fully removing the install later means
rejoining it.

**T-tap / Posi-Tap (reversible).** Clamp a tap onto the factory wire
without cutting it, leaving the OEM harness intact so the install
can be removed later with no trace. The tradeoff is a less robust
connection; use quality taps and check them.

The reference build used cut-and-splice with WAGOs. If keeping the
van's wiring fully reversible matters to you, use quality tap
connectors instead.

## Powering the board

```
12V source  →  buck converter (12V → 5V, USB-C out)  →  XIAO USB-C
```

Run the buck's input from your chosen 12V source (see
[Choosing a 12V source](#choosing-a-12v-source)) and its USB-C
output into the XIAO's USB-C port, reachable through the open rear
of the enclosure. The XIAO regulates 5V down to the 3V3 that powers the
board; 12V never reaches the PCB. See [HARDWARE.md](HARDWARE.md#power) for
the full power path and buck selection.

How 12V reaches the buck depends on the source you chose above:

- **House / leisure battery.** Mount the battery wherever it lives in
  the build and run a 12V feed forward to the buck under the center console.
- **Starter battery.** The easiest tap is the always-on 12V accessory
  (cigarette-lighter) socket, which sits in the same center console area as the
  master door lock switch. Splice or T-tap its constant-hot lead the same
  way you tapped the signal wires, after confirming it is constant
  power and not ignition-switched.

Mount the buck behind or under the center console near the enclosure so its
USB-C output is a short run into the XIAO through the open rear. Put a
small inline fuse (on the order of 1A, sized to the feed wire) in the
12V feed between the tap and the buck input, as close to the tap as
practical; the board's draw is tiny, so the fuse is there to protect
the added wiring, not the board.

## Seating the enclosure in the center console

<p align="center">
  <a href="media/t1n-smart-lock-enclosure-dash-seat-install-wired.jpeg">
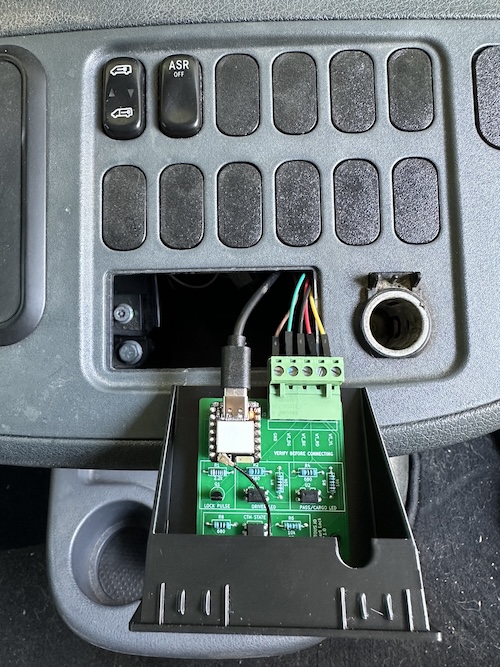
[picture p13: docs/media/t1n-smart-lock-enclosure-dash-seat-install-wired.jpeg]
Enclosure pulled out with J3 wires and USB-C connected, before seating
    
  </a>
  <a href="media/t1n-smart-lock-enclosure-dash-install.jpeg">
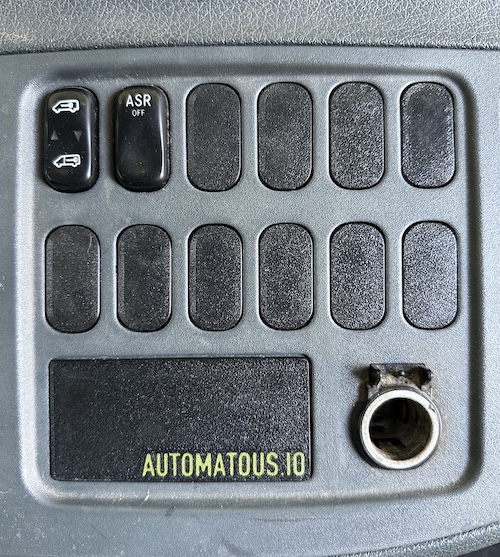
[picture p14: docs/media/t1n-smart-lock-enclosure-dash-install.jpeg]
Enclosure seated in the center console
    
  </a>
</p>

With the wiring connected and routed behind it, push the enclosure into
the factory center console opening where the factory storage pocket sat until the
front face is flush. It's a friction fit; no fasteners or modification
required.

To remove it later, hook a fingertip over the top edge and pull the
enclosure toward you; it lifts out of the friction fit.

## Confirming it's connected

The device was already commissioned on the bench (see
[Commission the device](#commission-the-device)), and commissioning is
stored on the device, so there's nothing to re-pair. Once powered in the van, it
rejoins your Thread network automatically. The status LED goes solid
when it's attached and operational (see
[Status LED reference](#status-led-reference)).

Open your Matter app and confirm the lock now reflects the van: with
the doors closed, locking and unlocking from the app should drive
the factory locks, and the lock/door state should track reality.
This is the first point at which lock state reads correctly, on the
bench the device responded but couldn't observe the van's LEDs.

Do this with the CTM awake. The firmware reads factory state through
the center console LEDs, and those are only lit while the CTM is
awake. Using the van, such as opening a door, wakes it; if the van has
sat undisturbed long enough for the CTM to sleep, the LEDs go dark and
the reported state freezes at its last known value until something
wakes it (see [Failure modes](SAFETY.md#failure-modes)). Right after
wiring and seating the enclosure the CTM is usually awake from your
activity, so confirm state then.

If the device does *not* appear or won't reconnect (for example, you
factory-reset it, or it was never commissioned), re-commission it:
with the device powered, add it in your Matter app using the QR code
/ setup code (same "Add Anyway" prompt as during bench commissioning,
see [Commission the device](#commission-the-device) and
[CERTIFICATION.md](CERTIFICATION.md#what-this-means-for-users)).

The device presents three things in your Matter app: a door lock and
two contact sensors, one for the driver side and one for the passenger,
cargo, and rear doors. The lock responds to Lock and Unlock; each contact
sensor reports its side as open or closed, following the factory door
state the firmware observes.

How these are grouped and named depends on the ecosystem. Apple Home
shows them under a single accessory that you can separate into a lock
and two sensors and rename (for example "T1N", "Driver", and "PAX").
Home Assistant's Matter integration exposes the lock as a `lock` entity
and each door contact sensor as a `binary_sensor`. The exact entity
names and `device_class` depend on the Home Assistant and Matter
integration version. The default names are auto-generated and differ by
app and version, so rename them to something meaningful after pairing.

<p align="center">
  <a href="media/t1n-smart-lock-home-with-doors.png">
    The lock and its two door contact sensors in Apple Home
  </a>
  <a href="media/t1n-smart-lock-home-firmware.png">
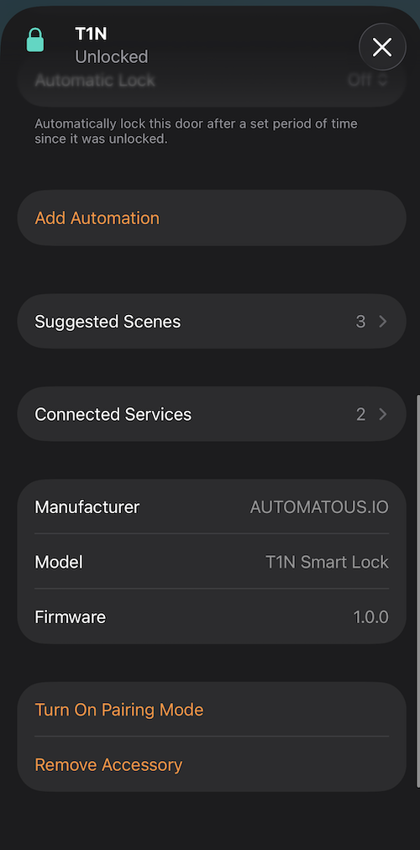
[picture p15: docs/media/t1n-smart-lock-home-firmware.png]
The accessory's firmware and details in Apple Home
    
  </a>
  <a href="media/t1n-smart-lock-ha.png">
    The same lock paired in Home Assistant
  </a>
</p>

## Status LED reference

The onboard status LED (on the XIAO) shows commissioning and network
state:

| LED pattern | Timing | Meaning |
|---|---|---|
| Rapid blink | 200ms on / 200ms off | Uncommissioned, advertising over BLE for pairing |
| Slow blink | 500ms on / 1500ms off | Commissioned, attaching to the Thread network |
| Solid on | Continuous | Connected to Thread, operational |
| Identify blink | 100ms on / 900ms off | Matter Identify command active |

Solid on is the healthy resting state.

## Factory reset

To wipe the device's Matter commissioning and reopen the pairing
window, **hold the BOOT button on the XIAO for 10 seconds.** The
device clears its commissioned state, reboots, and returns to BLE
advertising so it can be re-commissioned.

The BOOT button is not reachable with the enclosure seated in the
center console. Pull the enclosure out first (hook a fingertip over the top edge
and lift it from the friction fit, as in [Seating the enclosure in the
center console](#seating-the-enclosure-in-the-center-console)), hold BOOT for 10 seconds,
then reseat it.

You do not need a factory reset to add the lock to another ecosystem;
Matter is multi-admin (see
[Commission the device](#commission-the-device)). Use a reset to return
the device to a clean, uncommissioned state, for example before handing
it to someone else or when commissioning is broken. To re-flash the
firmware entirely (not just reset commissioning), see
[BUILDING.md](BUILDING.md#flash-your-build).

## Related documentation

- [README](../README.md) — project overview and quick start
- [FIRMWARE.md](FIRMWARE.md) — firmware architecture and behavior
- [HARDWARE.md](HARDWARE.md) — PCB design, BOM, and ordering
- [ENCLOSURE.md](ENCLOSURE.md) — 3D printed enclosure
- [BUILDING.md](BUILDING.md) — building and flashing the firmware
- [SAFETY.md](SAFETY.md) — electrical and operational safety
- [CERTIFICATION.md](CERTIFICATION.md) — Matter/Thread certification status
- [CONTRIBUTING.md](CONTRIBUTING.md) — how to contribute
- [LICENSING.md](LICENSING.md) — license terms

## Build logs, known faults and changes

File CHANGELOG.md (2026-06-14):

# Changelog

All notable changes to the T1N Smart Lock are recorded here. The
project ships three independently revised artifacts: the firmware, the
PCB, and the enclosure. Each can move on its own version line, so the
compatibility table below records which revisions are validated to work
together. Build a tagged commit to reproduce the exact combination in a
given row.

This project is distributed as source. There are no prebuilt binaries
or GitHub Releases. Firmware is built and flashed from source as
described in [docs/BUILDING.md](docs/BUILDING.md), and the managed component pins recorded
here are part of what defines a release.

## Compatibility

| Firmware | PCB | Enclosure | ESP-IDF | esp_matter | Validated on |
|---|---|---|---|---|---|
| 1.0.1 | v1.0 | v1.0 | 5.4.4 | 1.5.0 | 2005 Dodge Sprinter 2500 |
| 1.0.0 | v1.0 | v1.0 | 5.4.4 | 1.4.2~2 | 2005 Dodge Sprinter 2500 |

## 1.0.1 - 2026-06-14

Maintenance release. Firmware 1.0.1 on PCB v1.0 and enclosure v1.0.

Bumps the pinned `espressif/esp_matter` managed component from
`1.4.2~2` to `1.5.0` and adapts the contact sensor push to the 1.5
data model. In 1.5, BooleanState became a code driven cluster: its
`StateValue` is owned by the connectedhomeip `BooleanStateCluster`
object rather than the esp_matter attribute store, so the previous
`esp_matter::attribute::update` path returns `ESP_ERR_NOT_SUPPORTED`
and the driver/PAX door contacts silently stopped updating in Apple
Home and Home Assistant. The firmware now sets `StateValue` through the
cluster object retrieved from the data-model provider registry
(`SetStateValue`), restoring contact reporting. The lock endpoint is
unchanged; it already used the cluster setter
(`DoorLockServer::SetLockState`).

## 1.0.0 - 2026-06-12

First public release. Firmware 1.0.0, PCB v1.0, enclosure v1.0.

Open source observation-based Matter over Thread control of the factory
central locking, validated against a single vehicle. The firmware reads the
master door lock switch LEDs through optocouplers, senses the CTM rail
to detect sleep, and issues a CTM-aware lock command of one or two
pulses. It reports observed reality rather than commanded state. Full
behavior is documented in [docs/FIRMWARE.md](docs/FIRMWARE.md); this entry records the
release baseline rather than restating the feature set.

Known limitations/issues at release, with detail in [docs/FIRMWARE.md](docs/FIRMWARE.md):

- The classifier can commit a false CLOSED after a reboot with one or
  more doors held open for several minutes. It self-heals on the next
  physical door event. Observed 2026-05-31.
- OTA is present in the build but untested and unsupported in v1.0.
  Updates are flashed over USB-C from source.
- No per-side unlock. The CTM treats the master lock as a group, so all
  doors cycle together.
- An Unlock command with a door open still fires a pulse, since only the
  Lock path has the door-open check.
- Validated on one 2005 Dodge Sprinter 2500 only. Other years, markets,
  and trims are unverified.

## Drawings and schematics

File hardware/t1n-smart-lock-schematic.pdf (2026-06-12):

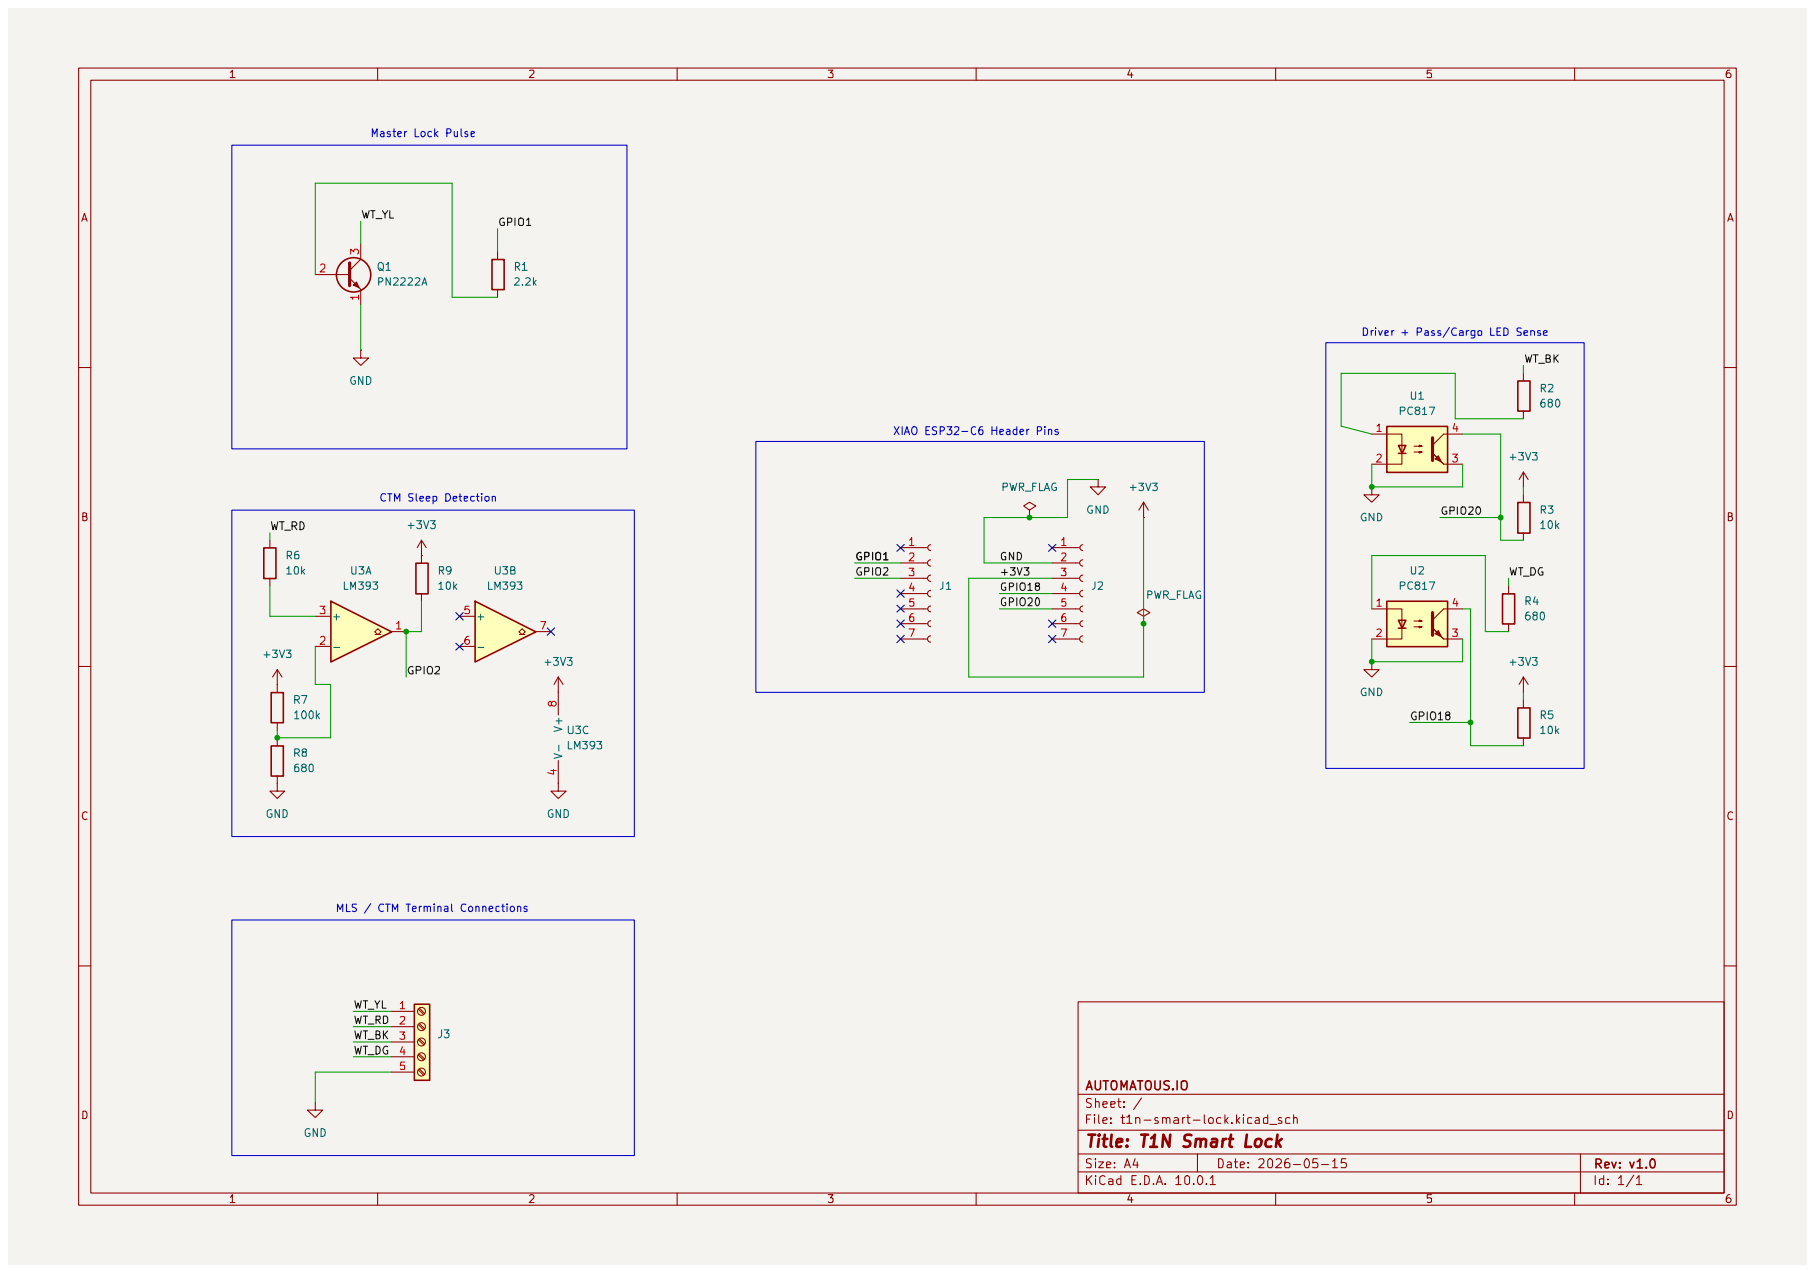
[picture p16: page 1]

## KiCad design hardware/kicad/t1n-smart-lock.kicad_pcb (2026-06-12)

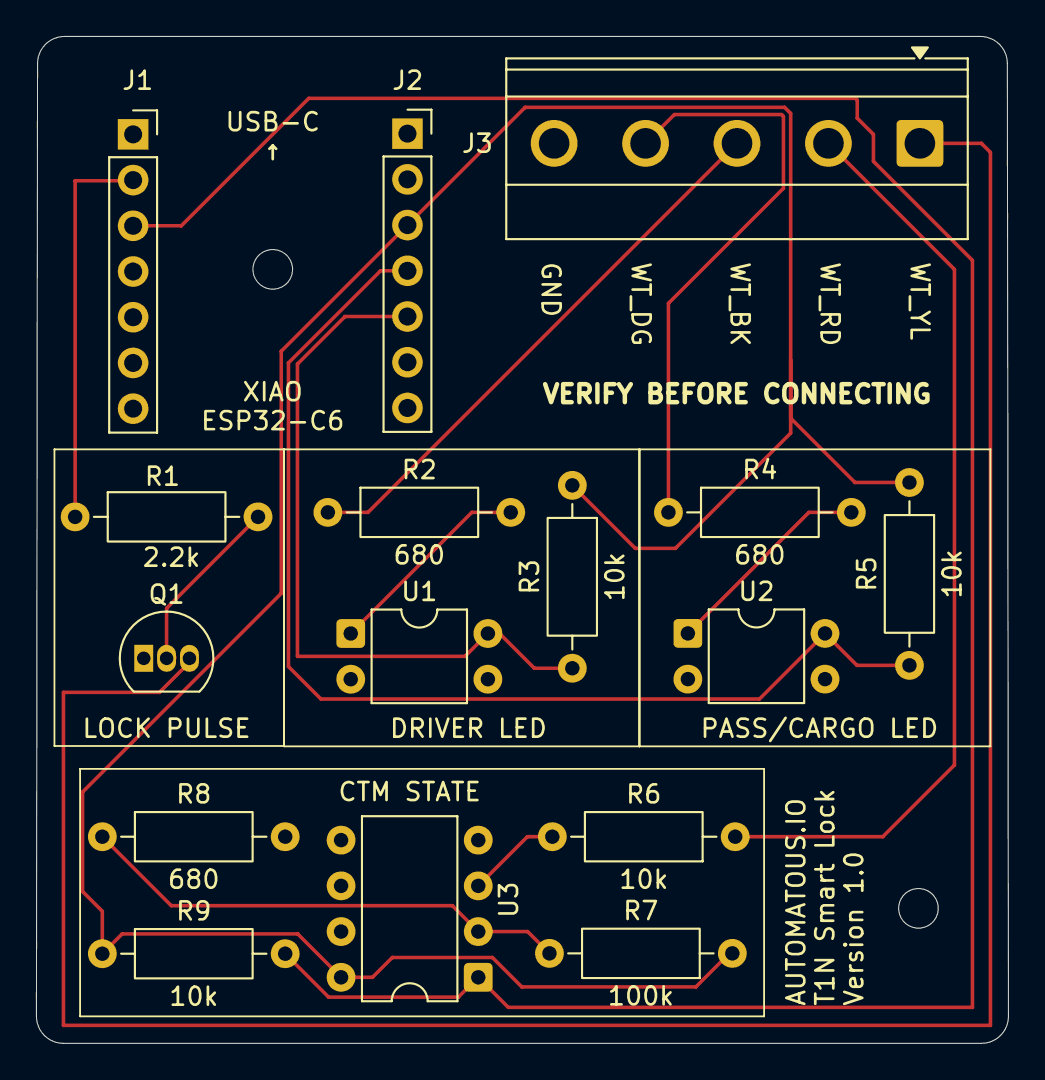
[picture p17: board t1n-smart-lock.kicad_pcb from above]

Board: 2 copper layers, 54.0 x 55.9 mm, 18 parts (0 on the bottom side), 15 nets.

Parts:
H1, H2: MountingHole_2.2mm_M2
J1, J2: Conn_01x07_Socket; PinSocket_1x07_P2.54mm_Vertical
J3: TerminalBlock_Phoenix_MKDS-1,5-5-5.08_1x05_P5.08mm_Horizont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
Q1: LOCK PULSE; TO-92_Inline
R1: 2.2k; R_Axial_DIN0207_L6.3mm_D2.5mm_P10.16mm_Horizontal
R2, R4, R8: 680; R_Axial_DIN0207_L6.3mm_D2.5mm_P10.16mm_Horizontal
R3, R5, R6, R9: 10k; R_Axial_DIN0207_L6.3mm_D2.5mm_P10.16mm_Horizontal
R7: 100k; R_Axial_DIN0207_L6.3mm_D2.5mm_P10.16mm_Horizontal
U1: DRIVER LED; DIP-4_W7.62mm
U2: PASS/CARGO LED; DIP-4_W7.62mm
U3: CTM STATE; DIP-8_W7.62mm

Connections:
+3V3: J2.3, R3.1, R5.1, R7.1, R9.1, U3.8 (V+)
/GPIO1: J1.2, R1.1
/GPIO2: J1.3, R9.2, U3.1
/GPIO18: J2.4, R5.2, U2.4
/GPIO20: J2.5, R3.2, U1.4
/WT_BK: J3.3, R2.1
/WT_DG: J3.4, R4.1
/WT_RD: J3.2, R6.1
/WT_YL: J3.1, Q1.3 (C)
GND: J2.2, J3.5, Q1.1 (E), R8.2, U1.2, U1.3, U2.2, U2.3, U3.4 (V-)
unnamed: Q1.2 (B), R1.2
unnamed: R2.2, U1.1
unnamed: R4.2, U2.1
unnamed: R6.2, U3.3 (+)
unnamed: R7.2, R8.1, U3.2 (-)

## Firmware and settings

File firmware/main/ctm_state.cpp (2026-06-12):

//
// Copyright 2025-2026 AUTOMATOUS.IO
//
// Licensed under the Apache License, Version 2.0 (the "License");
// you may not use this file except in compliance with the License.
// You may obtain a copy of the License at
//
//     http://www.apache.org/licenses/LICENSE-2.0
//
// Unless required by applicable law or agreed to in writing, software
// distributed under the License is distributed on an "AS IS" BASIS,
// WITHOUT WARRANTIES OR CONDITIONS OF ANY KIND, either express or implied.
// See the License for the specific language governing permissions and
// limitations under the License.
//

// ctm_state.cpp

#include "ctm_state.h"

#include "driver/gpio.h"
#include "esp_log.h"
#include "esp_timer.h"
#include "freertos/FreeRTOS.h"
#include "freertos/task.h"

#include <atomic>

static const char *TAG = "ctm_state";

// ---------------------------------------------------------------------------
// Hardware
// ---------------------------------------------------------------------------

// GPIO2: LM393 comparator output monitoring the WT_RD pulse train.
// Edges occur continuously in both CTM states; the rate is what
// differs. The instantaneous level is meaningless on its own.
#define CTM_GPIO  GPIO_NUM_2

// ---------------------------------------------------------------------------
// Detection parameters (validated 2026-05-24)
// ---------------------------------------------------------------------------

// Asleep ~238 edges/5s, awake ~448 edges/5s. Asleep sits 112 below
// the 350 threshold and awake 98 above it, safely outside the ±2
// measured variance.
static constexpr int CTM_AWAKE_THRESHOLD_5S = 350;

// 5-second sliding window matches the threshold tuning above.
static constexpr uint32_t CTM_WINDOW_MS = 5000;

// Raw state must hold this long before the official state flips.
// Defends against transients like the lock pulse spike.
static constexpr uint32_t CTM_STICKY_MS = 5000;

// Monitor task evaluation interval.
static constexpr uint32_t CTM_TICK_MS = 1000;

// At 89 Hz awake rate, 2048 entries hold ~23s of edge history. More
// than the 5s window needs, with cushion for the lock pulse spike
// (which can briefly hit ~170 Hz).
static constexpr int CTM_RING_SIZE = 2048;

// Task config
static constexpr uint32_t CTM_TASK_STACK_BYTES = 4096;
static constexpr UBaseType_t CTM_TASK_PRIORITY = 5;  // Matches status_led

// ---------------------------------------------------------------------------
// State (shared between ISR and monitor task)
// ---------------------------------------------------------------------------

// Edge timestamp ring buffer. ISR appends, monitor task reads a
// snapshot. edge_head is owned by the ISR.
static volatile uint32_t s_edge_times[CTM_RING_SIZE];
static volatile int s_edge_head = 0;

// Official state. Written only by monitor task; read from any task.
// Initialized asleep, the safe default for door_lock pulse selection.
static std::atomic<bool> s_official_awake{false};
static std::atomic<bool> s_initialized{false};

// Sticky classifier state. Owned by monitor task.
static bool s_raw_inferred_awake = false;
static int64_t s_raw_stable_since_us = 0;

// Callback slot. Atomic so registrations from any task are safe.
static std::atomic<ctm_state_changed_cb_t> s_callback{nullptr};

static TaskHandle_t s_task_handle = nullptr;

// ---------------------------------------------------------------------------
// ISR (edge detection on GPIO2)
// ---------------------------------------------------------------------------

static void IRAM_ATTR ctm_edge_isr(void *arg)
{
    // esp_timer_get_time is IRAM-safe and returns microseconds.
    // Storing as milliseconds keeps the math compact.
    uint32_t now_ms = (uint32_t)(esp_timer_get_time() / 1000);

    int head = s_edge_head;
    s_edge_times[head] = now_ms;
    s_edge_head = (head + 1) % CTM_RING_SIZE;
}

// ---------------------------------------------------------------------------
// Edge counting
// ---------------------------------------------------------------------------

// Walk ring buffer backwards from head, count edges within window.
static int count_edges_in_window(uint32_t now_ms, uint32_t window_ms)
{
    int head_snapshot = s_edge_head;
    int count = 0;

    for (int i = 0; i < CTM_RING_SIZE; i++) {
        int idx = (head_snapshot - 1 - i + CTM_RING_SIZE) % CTM_RING_SIZE;
        uint32_t ts = s_edge_times[idx];
        if (ts == 0) {
            // Unused slot, or ring wrapped past zero (extremely
            // unlikely since millis wraps at 49.7 days). Stop here.
            break;
        }
        if ((now_ms - ts) <= window_ms) {
            count++;
        } else {
            // Past the window. Older entries are out of scope.
            break;
        }
    }

    return count;
}

// ---------------------------------------------------------------------------
// Sticky classifier
// ---------------------------------------------------------------------------

static void update_classifier(int64_t now_us, bool raw_awake_now)
{
    if (raw_awake_now != s_raw_inferred_awake) {
        // Raw state just changed; restart sticky timer.
        s_raw_inferred_awake = raw_awake_now;
        s_raw_stable_since_us = now_us;
        return;
    }

    // Raw state hasn't changed since last tick. Stable long enough
    // to commit?
    int64_t stable_for_us = now_us - s_raw_stable_since_us;
    if (stable_for_us < (int64_t)CTM_STICKY_MS * 1000) {
        return;
    }

    // Stable long enough. Commit to official state if different.
    bool prev_official = s_official_awake.load();
    if (prev_official == s_raw_inferred_awake) {
        return;
    }

    s_official_awake.store(s_raw_inferred_awake);

    ESP_LOGI(TAG, "CTM state flip: %s -> %s.",
             prev_official ? "AWAKE" : "ASLEEP",
             s_raw_inferred_awake ? "AWAKE" : "ASLEEP");

    // Snapshot the callback pointer atomically to avoid racing with a
    // registration change mid-call.
    ctm_state_changed_cb_t cb = s_callback.load();
    if (cb != nullptr) {
        cb(s_raw_inferred_awake);
    }
}

// ---------------------------------------------------------------------------
// Monitor task
// ---------------------------------------------------------------------------
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

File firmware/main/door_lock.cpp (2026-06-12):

//
// Copyright 2025-2026 AUTOMATOUS.IO
// Portions derived from Espressif esp-matter examples,
// originally released into the public domain / CC0.
//
// Licensed under the Apache License, Version 2.0 (the "License");
// you may not use this file except in compliance with the License.
// You may obtain a copy of the License at
//
//     http://www.apache.org/licenses/LICENSE-2.0
//
// Unless required by applicable law or agreed to in writing, software
// distributed under the License is distributed on an "AS IS" BASIS,
// WITHOUT WARRANTIES OR CONDITIONS OF ANY KIND, either express or implied.
// See the License for the specific language governing permissions and
// limitations under the License.
//

// door_lock.cpp
//
// Matter Door Lock cluster glue. Receives Matter lock/unlock commands,
// reads CTM sleep state, requests pulse sequences from lock_pulse, and
// delegates credential/user/schedule storage to BoltLockMgr (Espressif
// example boilerplate in door_lock_manager.cpp).
//
// GPIO ownership lives in dedicated modules:
//   GPIO1  (lock pulse output)                   -> lock_pulse.cpp
//   GPIO2  (CTM sleep detect)                    -> ctm_state.cpp
//   GPIO18 (master door lock switch pax LED)     -> doors.cpp
//   GPIO20 (master door lock switch driver LED)  -> doors.cpp
//
// This file owns no hardware directly.
//
// lock_pulse_request() is non-blocking, so the Matter callback returns
// to Apple Home / HA optimistically (well under 1ms). The actual GPIO
// pulse fires asynchronously on lock_pulse_task. State verification of
// the result is currently not implemented (see TODO below).
//
// Two layers of cooldown protect the hardware:
//   - COMMAND_COOLDOWN_MS (2000ms): debounces user intent at the
//     Matter cluster level (mashed buttons, controller retries,
//     double-tap behaviors).
//   - 300ms in lock_pulse.cpp: hardware-level minimum spacing.
//
// TODO: post-pulse verification. lock_pulse already exposes a
// completion callback hook (lock_pulse_register_complete_cb). A
// future lock_attempt module would snapshot pre-pulse vehicle state,
// wait for the completion callback plus blackout window, read the
// post-pulse state from doors.cpp, and update the Matter lock state
// attribute to the actual result instead of optimistically.

#include <esp_log.h>
#include <esp_timer.h>
#include <freertos/FreeRTOS.h>
#include <freertos/task.h>
#include "door_lock_manager.h"
#include <lib/core/DataModelTypes.h>
#include <app/clusters/door-lock-server/door-lock-server.h>
#include "lock_pulse.h"
#include "ctm_state.h"
#include "doors.h"

#include <atomic>

static const char *TAG = "door_lock";

// Command-level cooldown. Minimum interval between consecutive
// Lock/Unlock commands at the Matter cluster level. This is the
// user-intent debounce layer; hardware protection lives in
// lock_pulse.cpp.
#define COMMAND_COOLDOWN_MS  2000

// Last command timestamp (microseconds since boot). Shared between
// Lock and Unlock: any command suppresses subsequent commands of
// either type during the cooldown window.
//
// Initialized to a value safely in the past so the first command
// after boot is never blocked by cooldown. Cannot use INT64_MIN
// because (now_us - INT64_MIN) overflows.
static std::atomic<int64_t> s_last_command_end_us{
    -(int64_t)COMMAND_COOLDOWN_MS * 1000 * 10};

static bool command_cooldown_check(const char *cmd_name)
{
    int64_t now_us = esp_timer_get_time();
    int64_t last_end_us = s_last_command_end_us.load();
    int64_t since_last_us = now_us - last_end_us;

    if (since_last_us < (int64_t)COMMAND_COOLDOWN_MS * 1000) {
        ESP_LOGW(TAG, "%s command rejected: cooldown active "
                 "(%lldms since last, need %dms).",
                 cmd_name, since_last_us / 1000, COMMAND_COOLDOWN_MS);
        return false;
    }
    return true;
}

static void command_cooldown_mark_complete(void)
{
    s_last_command_end_us.store(esp_timer_get_time());
}

// Request a pulse sequence sized for the current CTM state and
// lock-state asymmetry. See the comment in the function body for the
// pulse-count rules. Returns immediately; pulses fire on
// lock_pulse_task.
static void request_pulses_for_ctm_state(void)
{
    // Pulse count depends on CTM state and current lock-state asymmetry:
    //
    //   CTM asleep                       -> 2 pulses (pulse 1 wakes
    //                                       the CTM, pulse 2 toggles
    //                                       the lock)
    //   CTM awake, driver LOCKED,
    //     PAX UNLOCKED                   -> 2 pulses (pulse 1 syncs
    //                                       both to unlocked, pulse 2
    //                                       locks both)
    //   CTM awake, all other states      -> 1 pulse  (standard toggle)
    //
    // Hardware-characterized rule for the Sprinter CTM: from partial
    // state, a single lock pulse syncs the driver side to match PAX.
    // This is great when PAX is locked (driver follows up to LOCKED)
    // but wrong when PAX is unlocked (driver follows down to UNLOCKED,
    // opposite of user intent). Only the second case needs the extra
    // sync pulse first. See doors_lock_state_needs_sync_pulse for the
    // detection.
    //
    // Live classifier readings are used so the decision matches
    // current physical reality rather than the 10-second-lagged
    // stability gate. The user typically taps Lock right after an
    // exit pattern that produced the partial state, so the live
    // classifier is the right signal.
    bool ctm_asleep = !ctm_state_is_awake();
    bool needs_sync = doors_lock_state_needs_sync_pulse();
    int pulse_count = (ctm_asleep || needs_sync) ? 2 : 1;

    if (ctm_asleep) {
        ESP_LOGI(TAG, "CTM is asleep. Requesting 2-pulse wake+lock sequence.");
    } else if (needs_sync) {
        ESP_LOGI(TAG, "Driver locked, PAX unlocked. Requesting 2-pulse sync+lock sequence.");
    } else {
        ESP_LOGI(TAG, "CTM is awake. Requesting single lock pulse.");
    }

    lock_pulse_result_t result = lock_pulse_request(pulse_count);
    switch (result) {
        case LOCK_PULSE_RESULT_ENQUEUED:
            // Expected path; pulses will fire asynchronously.
            break;
        case LOCK_PULSE_RESULT_SUPPRESSED_COOLDOWN:
            ESP_LOGW(TAG, "Lock pulse cooldown active. Pulse not fired.");
            break;
        case LOCK_PULSE_RESULT_SUPPRESSED_BUSY:
            ESP_LOGW(TAG, "Lock pulse busy. Pulse not fired.");
            break;
        case LOCK_PULSE_RESULT_INVALID_COUNT:
            ESP_LOGE(TAG, "Lock pulse rejected count. This indicates a logic error.");
            break;
    }
    // Matter reports success regardless. See TODO at top of file
    // for post-pulse verification work.
}

// ---------------------------------------------------------------------------
// Linker anchor
// ---------------------------------------------------------------------------
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

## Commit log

2026-06-12 Initial public release of the T1N Smart Lock firmware, hardware (KiCad source, schematic, gerbers), 3D-printed enclosure, and full documentation. Open source Matter over Thread smart lock for the 200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
    [partitions.csv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]
2026-06-14 "Firmware 1.0.1: bump esp_matter 1.4.2~2 → 1.5.0, fix contact sensors esp_matter 1.5 makes BooleanState a code driven cluster, so attribute::update() on StateValue returns ESP_ERR_NOT_SUPPORTED and t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
    [doors.cpp]
